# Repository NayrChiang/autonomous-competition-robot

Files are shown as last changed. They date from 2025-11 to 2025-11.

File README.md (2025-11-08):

# Autonomous Competition Robot

An autonomous robot designed and built for competitive gameplay, integrating mechanical, electrical, and software systems. The robot autonomously identifies, transports, and positions scoring objects using infrared beacon tracking, Vive localization, wall-following, and PID motor control.

## Project Overview

**Course**: MEAM 5100 - Design of Mechatronic Systems  
**Institution**: University of Pennsylvania  
**Term**: Fall 2023

### Objective

Design and build an autonomous robot capable of identifying, transporting, and positioning objects on a competition field to maximize scoring potential while operating fully autonomously and handling opponent interference.

## Key Features

### Game Strategy
- Autonomous detection and manipulation of real vs. fake trophies via IR frequency recognition (550 Hz vs 23 Hz)
- Real-time navigation using Vive tracking and Time-of-Flight sensors
- Decision-making hierarchy prioritizing high-value tasks like trophy retrieval and police car pushing
- Adaptive recovery mechanisms for handling sensor or movement errors

### Autonomous Navigation
- PID-based motor control for smooth acceleration/deceleration
- Wall-following using dual TOF sensors for edge alignment and obstacle avoidance
- Real-time localization with Vive tracking and feedback-controlled path correction

### Object Manipulation
- Servo-actuated gripper for trophy handling
- Controlled pushing of the police car based on real-time Vive position updates
- Frequency-based classification for distinguishing object types

### Wireless Communication
- ESP-NOW + UDP networking for position broadcasting and communication multiplier compliance
- Fail-safe message retransmission mechanisms for reliability in high-interference environments

## System Architecture

### Mechanical Design
- Differential drive system (replacing Mecanum wheels) for improved traction
- Two-layer chassis design for weight distribution and stability
- Custom mounts for sensors and electronics
- 3D-printed components designed in SolidWorks

### Electrical System
- **Microcontroller**: ESP32-WROOM with modularized sensor architecture
- **Power System**: Dual-voltage power regulation (14.8 V LiPo → 12 V & 5 V)
- **Sensors**:
  - Dual Time-of-Flight (TOF) sensors (VL53L0X) for wall-following
  - Infrared sensors for beacon tracking and frequency detection
  - Encoders for motor feedback
- **Signal Processing**: Two-stage IR amplifier circuit for robust signal detection

### Software Architecture
- Modular state-machine architecture controlling modes (wall-following, beacon tracking, manual debug)
- PID motor control with encoder feedback
- Web-based control interface for debugging (HTML510 server)
- Real-time sensor data processing and fusion

## Technologies Used

- **Hardware**: ESP32-WROOM, Arduino IDE, SolidWorks
- **Programming**: C/C++, Embedded Systems
- **Control Systems**: PID Control, Motor Control
- **Sensors**: Infrared Sensors, Time-of-Flight Sensors (VL53L0X), Encoders
- **Localization**: Vive Tracking System
- **Communication**: ESP-NOW, UDP, WiFi, I2C, SPI, UART
- **Circuit Design**: Op-Amps, Filters, ADC

## Performance Metrics

- **Success Rate**: ~80% completion of all game objectives during trials
- **Trophy Detection Range**: Up to 2.5 m with < 0.5 s response time
- **Wall-following Accuracy**: < 5 cm lateral deviation
- **IR Frequency Detection**: < 0.5 s response time for 550 Hz vs 23 Hz classification

## Key Achievements

- Integrated mechanical, electrical, and software systems into a fully autonomous robot
- Achieved ~80% success rate in completing all game objectives during trials
- Implemented IR frequency detection (550 Hz vs 23 Hz) with < 0.5 s response time
- Developed PID-controlled differential drive with < 5 cm wall-following accuracy
- Integrated Vive tracking for real-time global localization and path correction
- Designed modular state-machine architecture supporting multiple operational modes
- Created dual-voltage power regulation (14.8 V LiPo → 12 V & 5 V)
- Built two-layer chassis for optimal weight distribution and stability

## Project Structure

```
autonomous-competition-robot/
├── code/
│   ├── Autonomous_Robot/
│   │   ├── Autonomous_Robot.ino    # Main robot control code
│   │   ├── html510.cpp             # Web server implementation
│   │   ├── html510.h
│   │   ├── vive510.cpp             # Vive tracking library
│   │   └── vive510.h
│   ├── Modular Codes/              # Modular code components
│   │   ├── ESPNow_VIve/
│   │   ├── ESPnow-receiver/
│   │   ├── ESPnow-sender/
│   │   ├── game-UDPreceiver/
│   │   └── tof_dual/
│   ├── esp_now.ino                 # ESP-NOW communication
│   ├── ir_detection.ino            # IR sensor code
│   ├── pid_controller.ino          # PID control implementation
│   ├── time_of_flight.ino          # TOF sensor code
│   ├── udp.ino                     # UDP communication
│   ├── vive.ino                    # Vive tracking code
│   └── web_controller.ino          # Web interface
├── cad-models/                     # SolidWorks CAD files
│   ├── Rover V2.SLDASM
│   ├── Chassis V2 - IR Layer.SLDPRT
│   ├── Chassis V2 - Motor Layer.SLDPRT
│   └── [other component files]
├── 2d-drawings/                    # 2D technical drawings
│   ├── 2D Drawing - Base Layer.pdf
│   ├── 2D Drawing - Caster Mount.pdf
│   ├── 2D Drawing - Power Bank Holder.pdf
│   └── 2D Drawing - Upper Layer.pdf
└── README.md
```

## Installation & Setup

### Prerequisites
- Arduino IDE (with ESP32 board support)
- ESP32-WROOM development board
- Required libraries:
  - `Adafruit_VL53L0X` (for TOF sensors)
  - `WiFi`, `WiFiUdp`, `esp_now` (ESP32 built-in)
  - Custom libraries: `html510`, `vive510`

### Hardware Setup
1. Assemble the robot chassis according to CAD models
2. Install sensors and electronics following the electrical design
3. Connect power system (14.8 V LiPo battery)
4. Configure WiFi network settings in code

### Software Setup
1. Install Arduino IDE and ESP32 board support
2. Install required libraries via Arduino Library Manager
3. Upload `Autonomous_Robot.ino` to the ESP32
4. Configure network settings (SSID, password, IP addresses)
5. Access web interface for debugging and manual control

## Usage

### Autonomous Mode
The robot operates autonomously, following these behaviors:
1. **Wall-following**: Uses dual TOF sensors to maintain distance from walls
2. **Beacon tracking**: Detects and approaches IR beacons (trophies)
3. **Frequency classification**: Distinguishes real (550 Hz) vs fake (23 Hz) trophies
4. **Object manipulation**: Grips and transports trophies to scoring zones
5. **Police car pushing**: Pushes police car based on Vive position updates

### Manual Control
Access the web interface at the robot's IP address to:
- Manually control motors and servos
- View sensor readings in real-time
- Debug and test individual components
- Monitor Vive tracking data

## License

This project is licensed under the Apache License 2.0 - see the [LICENSE](LICENSE) file for details.

## Acknowledgments

- MEAM 5100 course instructors and TAs
- Team members who contributed to the project
- University of Pennsylvania for providing resources and facilities

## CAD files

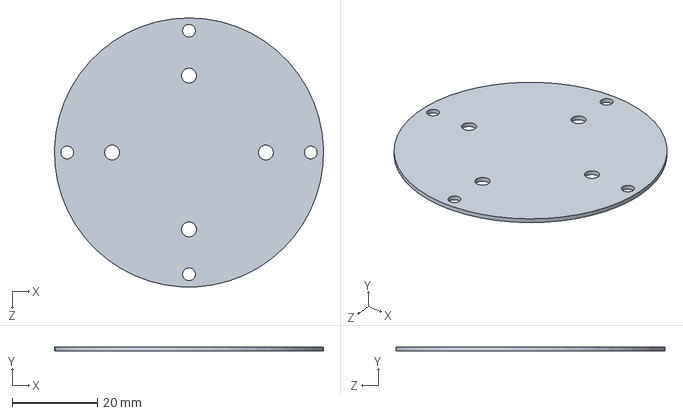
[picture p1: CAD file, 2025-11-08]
cad-models/Caster Mount.SLDPRT
63.0 x 1.00 x 63.0 mm

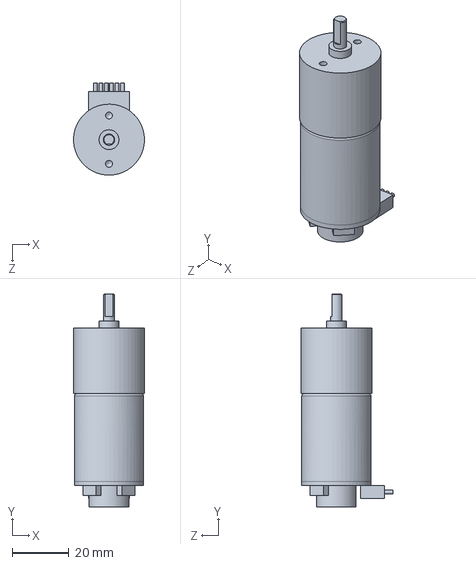
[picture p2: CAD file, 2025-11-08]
cad-models/DC Motor.SLDPRT
25.0 x 75.0 x 32.5 mm

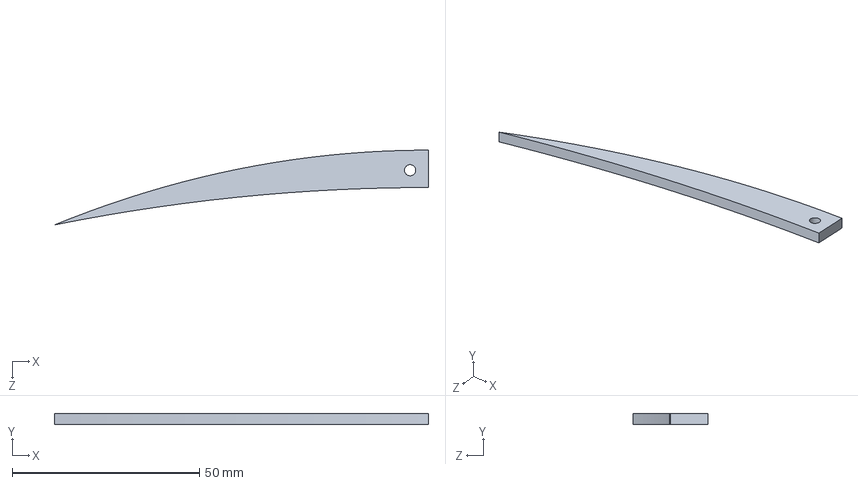
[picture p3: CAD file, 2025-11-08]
cad-models/Gripper.SLDPRT
100.0 x 3.00 x 20.0 mm

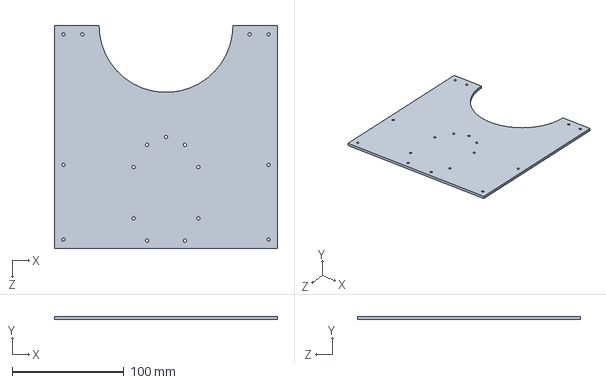
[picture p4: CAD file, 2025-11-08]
cad-models/Chassis V2 - IR Layer.SLDPRT
200.0 x 3.00 x 200.0 mm

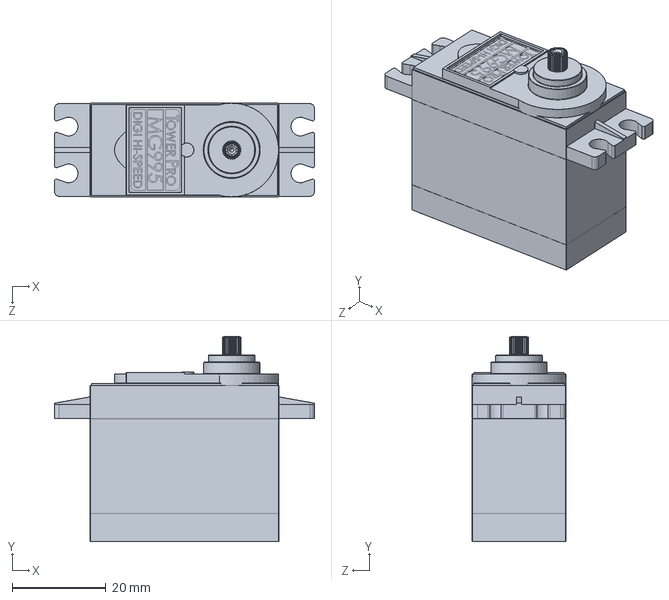
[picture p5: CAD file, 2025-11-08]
cad-models/Mg995.SLDPRT
55.5 x 43.8 x 20.0 mm

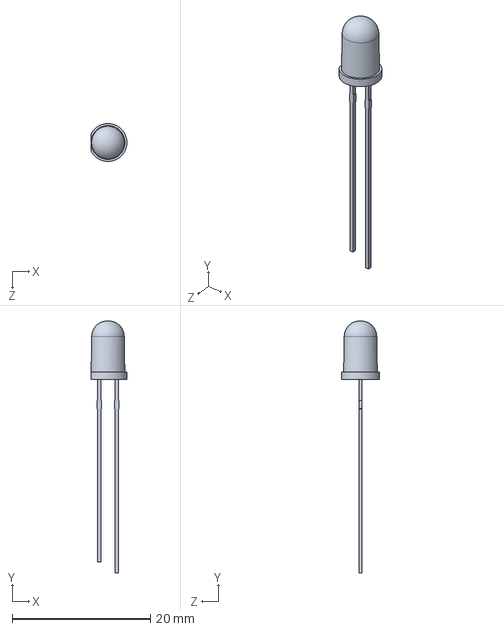
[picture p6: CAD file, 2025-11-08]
cad-models/LED 5mm.SLDPRT
5.20 x 36.5 x 5.50 mm

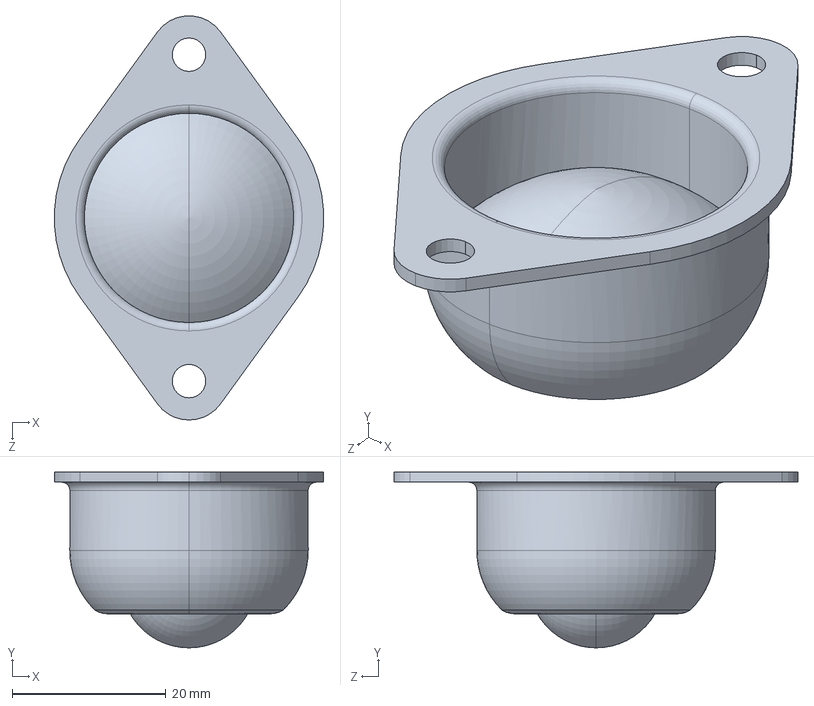
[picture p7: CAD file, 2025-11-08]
cad-models/Caster.SLDPRT
35.0 x 22.8 x 52.5 mm

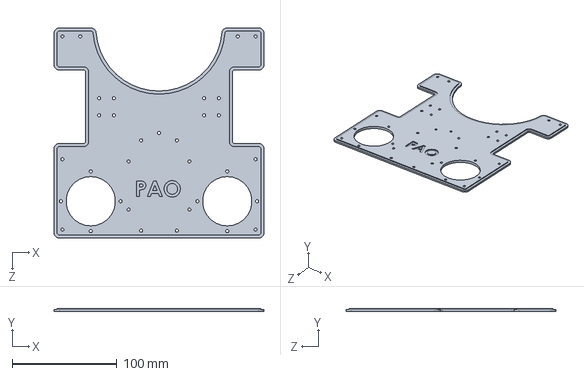
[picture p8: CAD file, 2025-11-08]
cad-models/Chassis V2 - Motor Layer.SLDPRT
200.0 x 3.00 x 200.0 mm

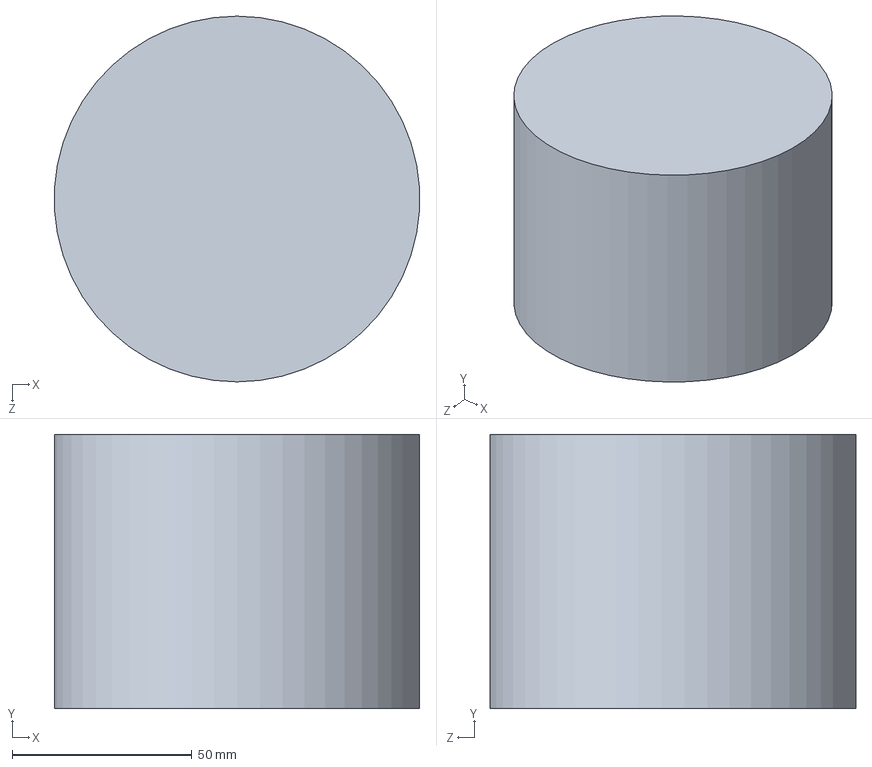
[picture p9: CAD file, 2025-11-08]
cad-models/Trophy.SLDPRT
101.4 x 76.2 x 101.6 mm

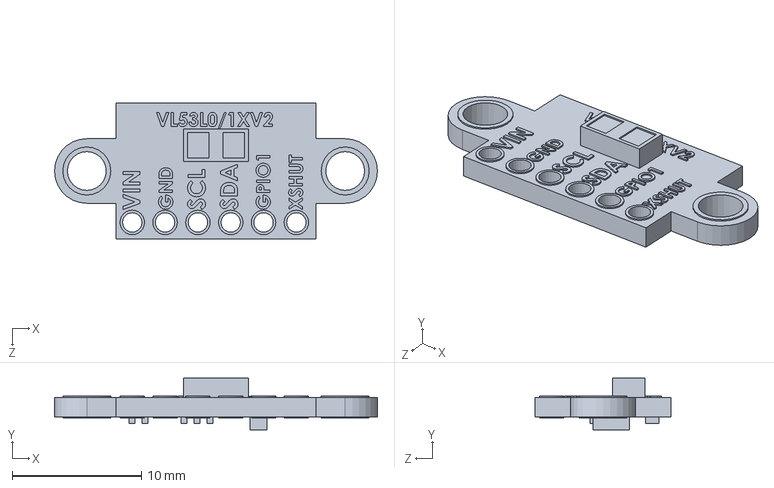
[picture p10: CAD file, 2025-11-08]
cad-models/VL53l1X.SLDPRT
25.0 x 4.00 x 10.5 mm

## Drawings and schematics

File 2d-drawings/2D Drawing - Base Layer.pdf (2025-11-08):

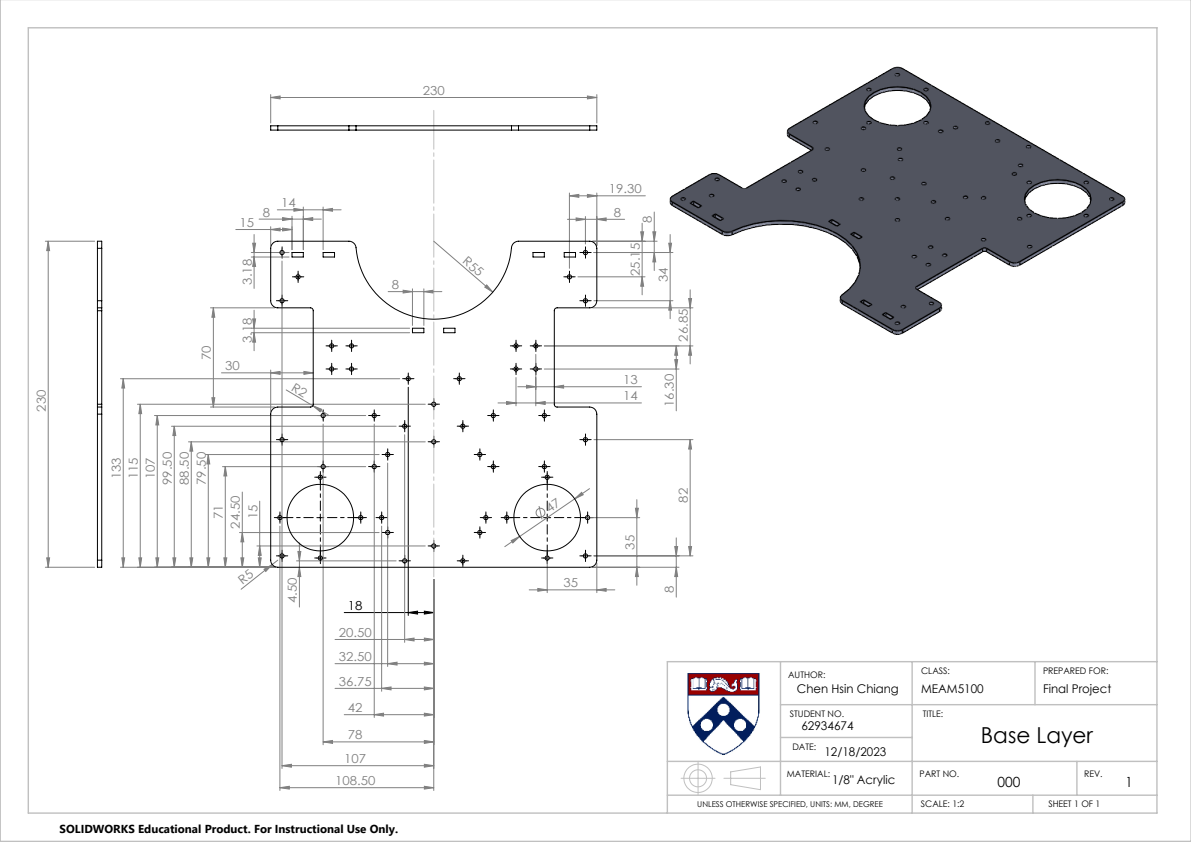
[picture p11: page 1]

AUTHOR: Chen Hsin Chiang | CLASS: MEAM5100 | PREPARED FOR: Final Project

STUDENT NO. 62934674 12/18/2023 DATE: | TITLE: Base Layer

MATERIAL: | PART NO. 1/8" Acrylic 000 | REV. 1

UNLESS OTHERWISE SPECIFIED, UNITS: MM, DEGREE | SCALE: 1:2 | SHEET 1 OF 1

SOLIDWORKS Educational Product. For Instructional Use Only.

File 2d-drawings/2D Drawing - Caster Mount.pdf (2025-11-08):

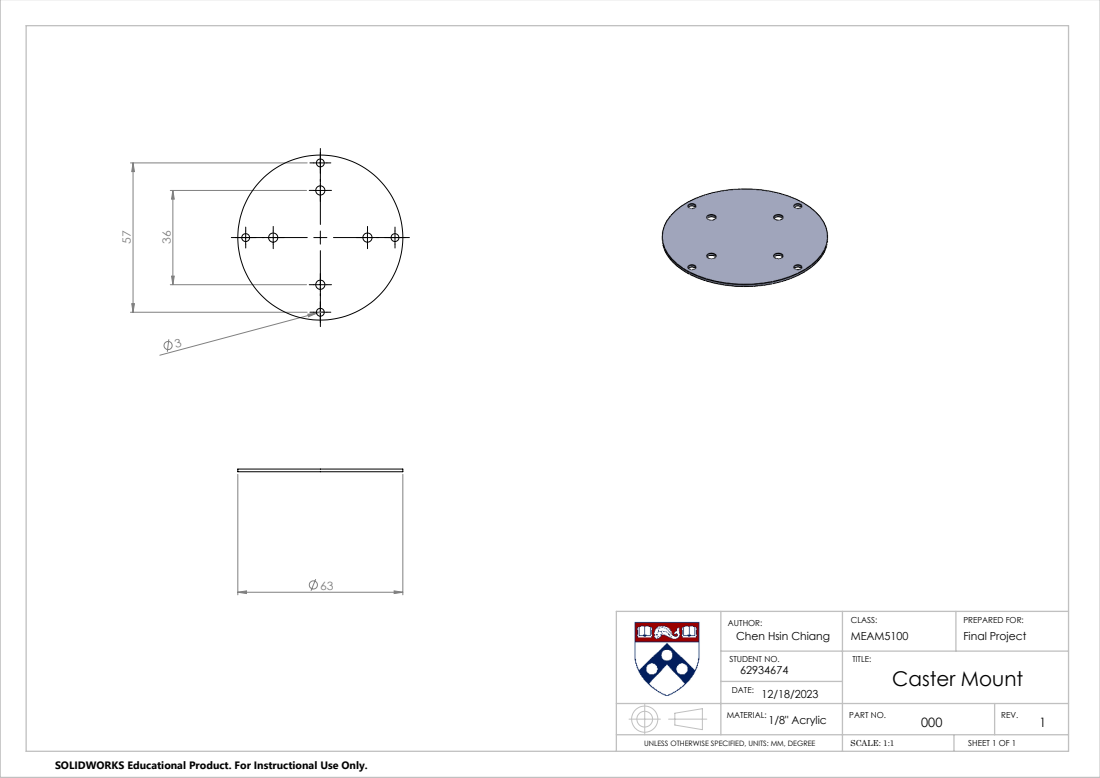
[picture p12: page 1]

AUTHOR: Chen Hsin Chiang | CLASS: MEAM5100 | PREPARED FOR: Final Project

STUDENT NO. 62934674 12/18/2023 DATE: | TITLE: Caster Mount

MATERIAL: | PART NO. 1/8" Acrylic 000 | REV. 1

UNLESS OTHERWISE SPECIFIED, UNITS: MM, DEGREE | SCALE: 1:1 | SHEET 1 OF 1

SOLIDWORKS Educational Product. For Instructional Use Only.

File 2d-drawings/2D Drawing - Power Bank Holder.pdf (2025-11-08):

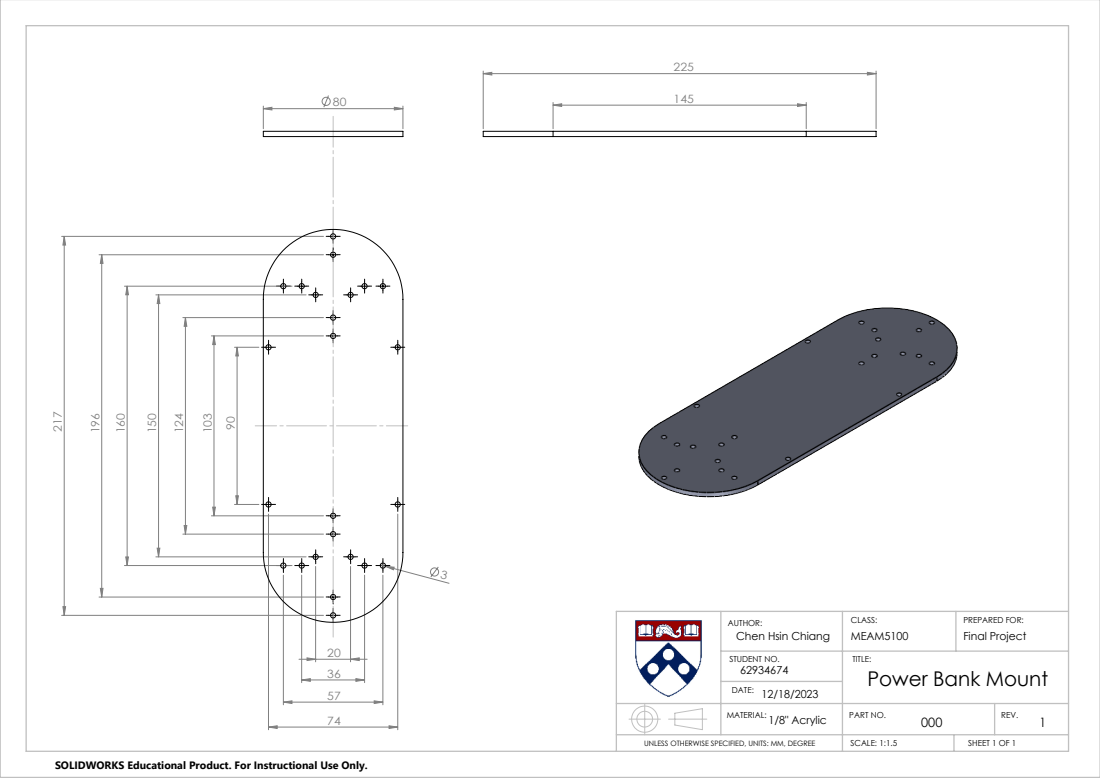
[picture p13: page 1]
SCALE: 1:1.5; SHEET 1 OF 1; PART NO. 1/8" Acrylic

AUTHOR: Chen Hsin Chiang | CLASS: MEAM5100 | PREPARED FOR: Final Project

STUDENT NO. 62934674 12/18/2023 DATE: | TITLE: Power Bank Mount

UNLESS OTHERWISE SPECIFIED, UNITS: MM, DEGREE

SOLIDWORKS Educational Product. For Instructional Use Only.

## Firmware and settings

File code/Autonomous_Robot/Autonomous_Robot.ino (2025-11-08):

/*
Version 12.12.18 (Final)
*/

// General Library
#include <WiFi.h>
#include <WiFiUdp.h>
#include <Wire.h>
#include <esp_now.h>
// Class and Installed Library
#include "html510.h"
#include "Adafruit_VL53L0X.h"
#include "vive510.h"

HTML510Server team24(80);    // Server Object for port 80 initialation the object with my name
// LEDC Setting
#define LEDC_RESOLUTION_BITS  14 // 2^13 = 4096
#define LEDC_RESOLUTION       ((1<<LEDC_RESOLUTION_BITS)-1) //4095
#define LEDC_FREQ_HZ          500
#define LEDC_CHANNEL1         0
#define LEDC_CHANNEL2         1
#define LEDC_VALUE_MAX        1500
// MOTOR Setting
#define MOTOR1_PIN1           25
#define MOTOR1_PIN2           26
#define MOTOR2_PIN1           27
#define MOTOR2_PIN2           14
#define ENCDPinMot1           16   // encoder pin of motor1
#define ENCDPinMot2           17  // encoder pin of motor2
#define PWMMoter1             32     // PWM pin of motor1
#define PWMMoter2             33     // PWM pin of motor2
// IR Setting
const int IRpins[] = {34,35};
int isHighPulse[] = {0,0};
unsigned long pulseDuration[] = {0,0};
float frequency[] = {0,0};
unsigned long lastAnalogValue[] = {0, 0};
int highThreshold = 2500; // Max 4096
// TOF Setting
#define SDA_PIN 21      // SDA Port
#define SCL_PIN 22      // SCL Port
#define LOX1_ADDRESS 0x30     // Address for two sensors
#define LOX2_ADDRESS 0x31
#define SHT_LOX1 18     // Shutdown Pin
#define SHT_LOX2 19
Adafruit_VL53L0X lox1 = Adafruit_VL53L0X();     // VL53L0X Object
Adafruit_VL53L0X lox2 = Adafruit_VL53L0X();
VL53L0X_RangingMeasurementData_t measure1;
VL53L0X_RangingMeasurementData_t measure2;
int TOF_Front = 0;
int TOF_Side = 0;
// WiFi Configuration
const char* ssid     = "Team Pao";
const char* password = "987654321";
WiFiUDP UDPTestServer;
IPAddress ipTarget(192, 168, 1, 255); // 255 => broadcast
IPAddress myIP(192, 168, 1, 217); // change to your IP
// Vive Wifi
#define RGBLED 2 // for ESP32S2 Devkit pin 2, for M5 stamp=2
#define SIGNALPIN1 13 // pin receiving signal from Vive circuit
#define UDPPORT 2510 // For GTA 2022C game 
#define teamNumber 24
#define FREQ 1 // in Hz
Vive510 vive1(SIGNALPIN1);
long int vive_ms = millis();
int police_x = 0;
int police_y = 0;
int vive_x = 0;
int vive_y = 0;

// ESPNow Parameters
#define CHANNEL 0                  // channel can be 1 to 14, channel 0 means current channel.  
// #define MAC_RECV  {0xa0,0x76,0x4e,0x19,0xea,0x2c} // receiver MAC address (last digit should be even for STA)
// Ryan Mac Address
// #define MAC_RECV  {0x68,0x67,0x25,0x82,0x3F,0x8C}
#define MAC_RECV  {0x60,0x55,0xF9,0x57,0x47,0x4C}
esp_now_peer_info_t peer1 = 
{
  .peer_addr = MAC_RECV, 
  .channel = CHANNEL,
  .encrypt = false,
};
// PID parameters
const int KP = 1.8;
const int KI = 0;
const int KD = 0.1;
int summederror[] = {0,0};
int oldSpeed[] = {0,0};
int desired = 0;  // PWM Value
int desired2 = 0;
int u[] = {0,0};
int u1 = 0;
int u2 = 0;
// Define variable for encoder
const int sensorPins[] = {9,10};  // Sensor pins
unsigned long preTime = 0;
unsigned long curTime = 0;
int numMotors = 2;
int count[] = {0,0};
int speed[] = {0,0};
int currentSensorState[] = {0,0};
int lastSensorState[] = {0,0};
// Rover Mode
int op_mode = 0; // Default: 0, Wall Following: 1, IR Seeking: 2, Police Car: 3

// Web Design
const char body[] PROGMEM = R"===(
<!DOCTYPE html>
<html lang="en">
<head>
    <meta charset="UTF-8">
    <title>Online HTML Editor</title>
    <style>
        /* Button styling */
        .button {
          padding: 15px 25px;
          font-size: 16px;
          text-align: center;
          cursor: pointer;
          outline: none;
          color: #fff;
          background-color: #04AA6D;
          border: none;
          border-radius: 5px;
          width: 150px;
          height: 50px;
          /* You can add more styling if needed, e.g., padding, margin, etc. */
          margin: 5px; /* Add margin for spacing between buttons */
        }
        
        .button1 {
          padding: 15px 25px;
          font-size: 16px;
          text-align: center;
          cursor: pointer;
          outline: none;
          color: #fff;
          background-color: #F70D1A;
          border: none;
          border-radius: 5px;
          width: 315px;
          height: 50px;
          /* You can add more styling if needed, e.g., padding, margin, etc. */
          margin: 5px; /* Add margin for spacing between buttons */
        }
   
        .button:hover {background-color: #3e8e41}
        .button1:hover {background-color: #990000}
   
        .button:active {
          background-color: #3e8e41;
          box-shadow: 0 5px #666;
          transform: translateY(4px);
        }
        .button1:active {
          background-color: #990000;
          box-shadow: 0 5px #666;
          transform: translateY(4px);
        }
        .slidecontainer {
          width: 100%; /* Width of the outside container */
        }
       
        /* The slider itself */
        .slider {
          -webkit-appearance: none;  /* Override default CSS styles */
          appearance: none;
          width: 60%; /* Full-width */
          height: 25px; /* Specified height */
          background: #d3d3d3; /* Grey background */
          outline: none; /* Remove outline */
          opacity: 0.7; /* Set transparency (for mouse-over effects on hover) */
          -webkit-transition: .2s; /* 0.2 seconds transition on hover */
          transition: opacity .2s;
        }
       
        /* Mouse-over effects */
        .slider:hover {
          opacity: 1; /* Fully shown on mouse-over */
        }
       
        /* The slider handle (use -webkit- (Chrome, Opera, Safari, Edge) and -moz- (Firefox) to override default look) */
        .slider::-webkit-slider-thumb {
          -webkit-appearance: none; /* Override default look */
          appearance: none;
          width: 25px; /* Set a specific slider handle width */
          height: 25px; /* Slider handle height */
          background: #04AA6D; /* Green background */
          cursor: pointer; /* Cursor on hover */
        }
       
        .slider::-moz-range-thumb {
          width: 25px; /* Set a specific slider handle width */
          height: 25px; /* Slider handle height */
          background: #04AA6D; /* Green background */
          cursor: pointer; /* Cursor on hover */
        }
    </style>
</head>
<body>
    <h1>Team 24 Final Project</h1>
    <button id="forwardButton" class="button">Forward</button>
    <button id="backwardButton" class="button">Backward</button><br>
    <button id="leftButton" class="button">Left</button>
    <button id="rightButton" class="button">Right</button> <br>
    <button id="leftRButton" class="button">LeftR</button>
    <button id="rightRButton" class="button">RightR</button> 
    
    <div>Duty Cycle 1 Controller</div>
    <div class="slidecontainer">
      <input type="range" min="1" max="100" value="50" class="slider" id="DutyCyc">
      <span id="DutyCycValue">50</span>%
    </div>

    <div>Duty Cycle 2 Controller</div>
    <div class="slidecontainer">
      <input type="range" min="1" max="100" value="50" class="slider" id="DutyCyc2">
      <span id="DutyCycValue2">50</span>%
    </div>
    
    <br>
    <button id="stopButton" class="button1">Stop</button>
    <br>
    <button id="mode_def" class="button">Default</button>
    <button id="mode_wall" class="button">Wall</button> 
    <button id="mode_ir" class="button">IR</button> 
    <button id="mode_pol" class="button">Police</button> 

    <script>
    document.getElementById('forwardButton').addEventListener('click', function() {
    var xhr = new XMLHttpRequest();
    xhr.open("GET", "/Forward", true);
    xhr.send();
    });

    document.getElementById('backwardButton').addEventListener('click', function() {
        var xhr = new XMLHttpRequest();
        xhr.open("GET", "/Backward", true);
        xhr.send();
    });

    document.getElementById('rightButton').addEventListener('click', function() {
    var xhr = new XMLHttpRequest();
    xhr.open("GET", "/Right", true);
    xhr.send();
    });

    document.getElementById('leftButton').addEventListener('click', function() {
        var xhr = new XMLHttpRequest();
        xhr.open("GET", "/Left", true);
        xhr.send();
    });
    
    document.getElementById('rightRButton').addEventListener('click', function() {
    var xhr = new XMLHttpRequest();
    xhr.open("GET", "/RightR", true);
    xhr.send();
    });

    document.getElementById('leftRButton').addEventListener('click', function() {
        var xhr = new XMLHttpRequest();
        xhr.open("GET", "/LeftR", true);
        xhr.send();
    });
    
    document.getElementById('stopButton').addEventListener('click', function() {
        var xhr = new XMLHttpRequest();
        xhr.open("GET", "/Stop", true);
        xhr.send();
    });

    document.getElementById('mode_def').addEventListener('click', function() {
        var xhr = new XMLHttpRequest();
        xhr.open("GET", "/M_Def", true);
        xhr.send();
    });

    document.getElementById('mode_wall').addEventListener('click', function() {
        var xhr = new XMLHttpRequest();
        xhr.open("GET", "/M_Wall", true);
        xhr.send();
    });

    document.getElementById('mode_ir').addEventListener('click', function() {
        var xhr = new XMLHttpRequest();
        xhr.open("GET", "/M_IR", true);
        xhr.send();
    });

    document.getElementById('mode_pol').addEventListener('click', function() {
        var xhr = new XMLHttpRequest();
        xhr.open("GET", "/M_Pol", true);
        xhr.send();
    });

    document.addEventListener('keyup', function() {
        var xhr = new XMLHttpRequest();
        xhr.open("GET", "/Stop", true);
        xhr.send();
    });

    document.body.addEventListener('keydown', function(event) {
      var xhr = new XMLHttpRequest();

      switch (event.key.toUpperCase()) {
          case 'W':
              xhr.open("GET", "/Forward", true);
              xhr.send();
              break;
          case 'S':
              xhr.open("GET", "/Backward", true);
              xhr.send();
              break;
          case 'A':
              xhr.open("GET", "/LeftR", true);
              xhr.send();
              break;
          case 'D':
              xhr.open("GET", "/RightR", true);
              xhr.send();
              break;
          case ' ':
              xhr.open("GET", "/Stop", true);
              xhr.send();
              break;
      }
    });

    document.body.addEventListener('keydown', function(event) {
    var xhr = new XMLHttpRequest();

    // Check if the pressed key is one of the arrow keys
    if (event.key === 'o' || event.key === 'k') {
        // Increment or decrement the slider value
        var step = event.key === 'o' ? 1 : -1;
        pwmSlider.value = Math.min(100, Math.max(0, parseInt(pwmSlider.value) + step));

        // Update the displayed value
        pwmOutput.innerHTML = pwmSlider.value;

        // Send the updated value to the server
        xhr.open("GET", "/sliderDutyCyc?val=" + pwmSlider.value, true);
        xhr.send();

        // Prevent the default behavior of arrow keys (e.g., scrolling the page)
        event.preventDefault();
    }
    if (event.key === 'p' || event.key === 'l') {
        // Increment or decrement the slider value
        var step = event.key === 'p' ? 1 : -1;
        pwmSlider2.value = Math.min(100, Math.max(0, parseInt(pwmSlider2.value) + step));

        // Update the displayed value
        pwmOutput2.innerHTML = pwmSlider2.value;

        // Send the updated value to the server
        xhr.open("GET", "/sliderDutyCyc2?val=" + pwmSlider2.value, true);
        xhr.send();

        // Prevent the default behavior of arrow keys (e.g., scrolling the page)
        event.preventDefault();
    }
    });

    // PWM Slider
    var pwmSlider = document.getElementById("DutyCyc");
    var pwmOutput = document.getElementById("DutyCycValue");
    pwmOutput.innerHTML = pwmSlider.value; // Display the default slider value
    pwmSlider.oninput = function() {
        pwmOutput.innerHTML = this.value;
        var xhr = new XMLHttpRequest();
        xhr.open("GET", "/sliderDutyCyc?val=" + this.value, true);
        xhr.send();
    }; 

    var pwmSlider2 = document.getElementById("DutyCyc2");
    var pwmOutput2 = document.getElementById("DutyCycValue2");
    pwmOutput2.innerHTML = pwmSlider2.value; // Display the default slider value
    pwmSlider2.oninput = function() {
        pwmOutput2.innerHTML = this.value;
        var xhr = new XMLHttpRequest();
        xhr.open("GET", "/sliderDutyCyc2?val=" + this.value, true);
        xhr.send();
    }; 
    </script>
</body>
</html>
)===";

// Handler Functions
// HTML content Handle
void handleRoot(){
  team24.sendhtml(body);
}

//Forward Handle
void handleForward(){
  mForward();
  team24.sendhtml(body);
  // espSend();
}

//Backward Handle
void handleBackward(){
  mBackward();
  team24.sendhtml(body);
  // espSend();
}

// One Spin one idle
// Left Handle 
void handleLeft(){
  mLeft();
  team24.sendhtml(body);
  // espSend();
}

// Right Handle
void handleRight(){
  mRight();
  team24.sendhtml(body);
  // espSend();
}

// R for revolute
void handleLeftR(){
  mLeftR();
  team24.sendhtml(body);
  // espSend();
}

// Right Handle
void handleRightR(){
  mRightR();
  team24.sendhtml(body);
  // espSend();
}

void handleStop(){
  mStop();
  team24.sendhtml(body);
  // espSend();
}

//Duty Cycle Handle
void handleSliderDutyCyc(){
  desired = LEDC_VALUE_MAX * team24.getVal()/100; // Desired desiredDutyCyc
  Serial.printf("The desiredDutyCyc is: ");
  Serial.println(desired);
  // espSend();
}

void handleSliderDutyCyc2(){
  desired2 = LEDC_VALUE_MAX * team24.getVal()/100; // Desired desiredDutyCyc
  Serial.printf("The desiredDutyCyc2 is: ");
  Serial.println(desired2);
  // espSend();
}

void handleMode_Def() {
  op_mode = 0;
  team24.sendhtml(body);
  Serial.println("Switch to Default");
  espSend();
}

void handleMode_Wall() {
  op_mode = 1;
  team24.sendhtml(body);
  espSend();
}

void handleMode_IR() {
  op_mode = 2;
  team24.sendhtml(body);
  espSend();
}

void handleMode_Pol() {
  op_mode = 3;
  team24.sendhtml(body);
  Serial.println("Switch to Police Mode");
  espSend();
}

void setup_handler(){
  team24.attachHandler("/", handleRoot);
  team24.attachHandler("/Forward", handleForward);
  team24.attachHandler("/Backward", handleBackward);
  team24.attachHandler("/Right", handleRight);
  team24.attachHandler("/Left", handleLeft);
  team24.attachHandler("/RightR", handleRightR);
  team24.attachHandler("/LeftR", handleLeftR);
  team24.attachHandler("/Stop", handleStop);
  team24.attachHandler("/sliderDutyCyc?val=", handleSliderDutyCyc);
  team24.attachHandler("/sliderDutyCyc2?val=", handleSliderDutyCyc2);
  team24.attachHandler("/M_Def", handleMode_Def);
  team24.attachHandler("/M_Wall", handleMode_Wall);
  team24.attachHandler("/M_IR", handleMode_IR);
  team24.attachHandler("/M_Pol", handleMode_Pol);
}

// Motor Functions
void encoder(){
  // Read the current state of the sensor
  curTime = millis();

  for (int i=0; i<numMotors; i++){
    currentSensorState[i] = digitalRead(sensorPins[i]);
    if (currentSensorState[i] != lastSensorState[i]) {
      if (currentSensorState[i] == HIGH) {
        count[i]++;
      }
    lastSensorState[i] = currentSensorState[i];
    }
  }

  if (curTime - preTime >= 100) {
    for (int i=0; i<numMotors; i++){
      // Calculate speed as interrupts per second
      speed[i] = 60.0/11.0*count[i];
      // Reset the interrupt count and the preTime to the current time
      count[i] = 0;
      preTime = curTime;
    }
  } else if (curTime < preTime) {
    // Handle the case of millis() overflow
    preTime = curTime;
  }
}

void mForward(){
  digitalWrite(MOTOR1_PIN1, HIGH);
  digitalWrite(MOTOR1_PIN2, LOW);
  digitalWrite(MOTOR2_PIN1, HIGH);
  digitalWrite(MOTOR2_PIN2, LOW);
  Serial.println("Forward");
}

void mBackward(){
  digitalWrite(MOTOR1_PIN1, LOW);
  digitalWrite(MOTOR1_PIN2, HIGH);
  digitalWrite(MOTOR2_PIN1, LOW);
  digitalWrite(MOTOR2_PIN2, HIGH);
  Serial.println("Back");
}

void mLeft(){
  digitalWrite(MOTOR1_PIN1, LOW);
  digitalWrite(MOTOR1_PIN2, LOW);
  digitalWrite(MOTOR2_PIN1, HIGH);
  digitalWrite(MOTOR2_PIN2, LOW);
  Serial.println("Left R");
}

void mRight(){
  digitalWrite(MOTOR1_PIN1, HIGH);
  digitalWrite(MOTOR1_PIN2, LOW);
  digitalWrite(MOTOR2_PIN1, LOW);
  digitalWrite(MOTOR2_PIN2, LOW); 
  Serial.println("Right R"); 
}

void mLeftR(){
  digitalWrite(MOTOR1_PIN1, LOW);
  digitalWrite(MOTOR1_PIN2, HIGH);
  digitalWrite(MOTOR2_PIN1, HIGH);
  digitalWrite(MOTOR2_PIN2, LOW);
  Serial.println("Left R");
}

void mRightR(){
  digitalWrite(MOTOR1_PIN1, HIGH);
  digitalWrite(MOTOR1_PIN2, LOW);
  digitalWrite(MOTOR2_PIN1, LOW);
  digitalWrite(MOTOR2_PIN2, HIGH); 
  Serial.println("Right R"); 
}

void mStop(){
  digitalWrite(MOTOR1_PIN1, HIGH);
  digitalWrite(MOTOR1_PIN2, HIGH);
  digitalWrite(MOTOR2_PIN1, HIGH);
  digitalWrite(MOTOR2_PIN2, HIGH);
  Serial.println("Stop R");  
}

// Write duty to LEDC
void ledcAnalogWrite(uint8_t channel, uint32_t value, uint32_t valueMax = LEDC_VALUE_MAX) {            
  uint32_t duty =  LEDC_RESOLUTION * min(value, valueMax) / valueMax;  
  ledcWrite(channel, duty);  
}

void setup_motor(){
  // Setup for Motor speed
  ledcSetup(LEDC_CHANNEL1, LEDC_FREQ_HZ, LEDC_RESOLUTION_BITS);
  ledcSetup(LEDC_CHANNEL2, LEDC_FREQ_HZ, LEDC_RESOLUTION_BITS);
  ledcAttachPin(PWMMoter1, LEDC_CHANNEL1);
  ledcAttachPin(PWMMoter2, LEDC_CHANNEL2);

  // set motor control pins as output
  pinMode(MOTOR1_PIN1, OUTPUT); 
  pinMode(MOTOR1_PIN2, OUTPUT); 
  pinMode(MOTOR2_PIN1, OUTPUT);
  pinMode(MOTOR2_PIN2, OUTPUT); 
}

void PIDControl() {
  // Iterate over each motor in the system
  for (int i = 0; i < numMotors; i++) {
    // Calculate the velocity, which is the change in speed
    int velocity = speed[i] - oldSpeed[i];
    // Update the cumulative error by adding the current error (difference between desired speed and current speed)
    summederror[i] += (desired - speed[i]);
    // PID Control Calculation:
    u[i] = KP * (desired - speed[i]) + KD * velocity + KI * summederror[i];
    // Adjust summed error if the motor speed is more than desired speed
    if (desired - speed[i] < 0) summederror[i] *= 0.5;
    // Limit the maximum value of summed error to prevent integral wind-up
    if (summederror[i] > 3000) summederror[i] = 3000;
    // Limit the control signal to a maximum value
    if (u[i] > 1500) u[i] = 1500;
    // Ensure the control signal is not negative
    if (u[i] < 0) u[i] = 0;
    // Update oldSpeed for the next iteration
    oldSpeed[i] = speed[i];
  }
}


// WiFi Functions
void UdpSend(int x, int y){
  char udpBuffer[20];
  sprintf(udpBuffer, "%02d:%4d,%4d",teamNumber,x,y);   
  UDPTestServer.beginPacket(ipTarget, UDPPORT);
  UDPTestServer.println(udpBuffer);
  UDPTestServer.endPacket();
  Serial.println(udpBuffer);
}

void handleUDPServer() {
   const int UDP_PACKET_SIZE = 14; // can be up to 65535          
   uint8_t packetBuffer[UDP_PACKET_SIZE];

   int cb = UDPTestServer.parsePacket(); // if there is no message cb=0
   if (cb) {
      packetBuffer[13]=0; // null terminate string
      UDPTestServer.read(packetBuffer, UDP_PACKET_SIZE);
      if (atoi((char *)packetBuffer) == 0) {
        police_x = atoi((char *)packetBuffer+3); // ##,####,#### 2nd indexed char
        police_y = atoi((char *)packetBuffer+8); // ##,####,#### 7th indexed char
        Serial.print("From Team ");
        Serial.println((char *)packetBuffer);
        Serial.println("Police Car data: ");
        Serial.println(police_x);
        Serial.println(police_y);
      }      
   }
}
// ESPNow
// callback when data is sent 
void OnDataSent(const uint8_t *mac_addr, esp_now_send_status_t status) {
  if (status == ESP_NOW_SEND_SUCCESS) Serial.println ("Success ");
  else Serial.println("Fail "); 
}

void setup_wifi(){
  Serial.println("AP Mode");
  WiFi.mode(WIFI_AP_STA); 
  IPAddress myIP(192,168,1,132);
  // Set WiFi to AP mode
  WiFi.softAP(ssid, password);
  WiFi.softAPConfig(myIP, IPAddress(192,168,1,1), IPAddress(255,255,255,0));
  Serial.printf("Connected to %s on ", ssid); 
  Serial.println(myIP);  //Print ssid and IP address

  // Vive
  Serial.printf("Team  #%d", teamNumber); 
  UDPTestServer.begin(UDPPORT);
  vive1.begin();
  Serial.println("Vive trackers started");

  // ESPNow
  Serial.print("Sending MAC: "); Serial.println(WiFi.macAddress());
  if (esp_now_init() != ESP_OK) {
    Serial.println("ESPnow init failed");
    ESP.restart();
  }
  esp_now_register_send_cb(OnDataSent); //optional if you want ack interrupt
  if (esp_now_add_peer(&peer1) != ESP_OK) {
    Serial.println("ESPnow Pair failed");     // ERROR  should not happen
  }
}
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
void loop() {
  team24.serve();  
  frequency[0] = 0;
  frequency[1] = 0;
  IRDetect();
  if (op_mode == 0) {
    // Default    
    encoder();
    PIDControl();
    ledcAnalogWrite(LEDC_CHANNEL1, u[0]); // motor1
    ledcAnalogWrite(LEDC_CHANNEL2, u[1]); // motor2
  }
  else if (op_mode == 1) {
    // Wall Following
    Serial.println("Wall Following...");
    read_dual_sensors();
    wall_following();
  }
  else if (op_mode == 2) {
    // IR Mode
    mLeftR();
    delay(110);
    mStop();
    if (abs(frequency[0]-550)<50){
      mForward();
      delay(900);
      mStop();
    }

  }
  else if (op_mode == 3) {
    // Police Car
    mStop();
    ledcAnalogWrite(LEDC_CHANNEL1, 1200); // motor1
    ledcAnalogWrite(LEDC_CHANNEL2, 1200); // motor2
    move_to_pol();
  } 

}

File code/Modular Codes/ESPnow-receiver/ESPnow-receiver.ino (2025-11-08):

/**
 *  ESP NOW testing generic receiver no sending
 *  Simple setup, print packets as received.
**/

#include <esp_now.h>
#include <WiFi.h>

// callback on receive
void OnDataRecv(const uint8_t *mac_addr, const uint8_t *data, int data_len) {
  Serial.printf(" Recv from: %02x:%02x:%02x:%02x:%02x:%02x ",mac_addr[0], mac_addr[1], mac_addr[2], mac_addr[3], mac_addr[4], mac_addr[5]); 
  Serial.print(" Data: "); 
  if (isascii(data[0])) Serial.println( (char *)data);
  else {
    for (int i=0; i<data_len; i++ ){
      Serial.printf("%x",data[i]); if (i%3==0) Serial.print(" ");
    }
  }
}

void setup() {
  Serial.begin(115200);
  WiFi.mode(WIFI_STA);
  Serial.print("ESPNow Receiving MAC: ");  Serial.println(WiFi.macAddress());
  Serial.print("Sending MAC: "); Serial.println(WiFi.macAddress());

  if (esp_now_init() != ESP_OK) {
    Serial.println("ESPNow Init Failed");
    ESP.restart();
  }
  esp_now_register_recv_cb(OnDataRecv);    
}

void loop() {
}
